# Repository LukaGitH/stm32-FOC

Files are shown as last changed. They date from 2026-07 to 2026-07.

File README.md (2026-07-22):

# Field-Oriented Control (FOC) on STM32 From Scratch

This project demonstrates a complete, low-level implementation of **Field-Oriented Control (FOC)** for controlling a **BLDC motor** using an **STM32F4 microcontroller**, without relying on high-level motor control libraries.

Built using **PlatformIO**, **STM32 HAL/LL drivers**, and **FreeRTOS**, this project is designed for learning and practical experimentation in precision motor control.

---

## Features Implemented

- Clarke & Park Transforms  
- Position feedback via AS5047 encoder  
- Phase current sampling via ADC  
- SVPWM (Space Vector PWM) generation  
- Torque Control
- Speed Control
- Position Control
- Encoder auto calibration
- Self-Commissioning for PI Gain current controller auto tuning
- Sensorless mode using Sliding Mode Observer (SMO) & High Frequency Injection (HFI)
- USB CDC interface for real-time tuning and monitoring  
- Save configuration to flash memory
- Interrupt-driven timing and FreeRTOS tasking  

---

## Development Tools

- [PlatformIO](https://platformio.org/)
- STM32CubeMX
- STM32Cube HAL & LL Drivers  
- FreeRTOS (via PlatformIO package)  
- VS Code + Serial Monitor for debugging
- KiCad 9 (hardware project in [`STM32-FOC-hardware/ESC-BLDC`](STM32-FOC-hardware/ESC-BLDC))
- Controller application source in `lib/Controller_app/` (archive:
  `controler_appv2.zip`)

---

## Simple Command Line Interface (CLI)

- change control mode: `mode <mode>`  
`<mode>`:  
  `0` -> torque/current control  
  `1` -> speed control  
  `2` -> position control  
- change set point: `sp <value>`  
- run self commissioning: `calib`  
- read motor parameters: `motor_param`  
- read all PID parameters: `pid <control>`  
`<control>`:  
  `id` -> direct current control  
  `iq` -> quadrature current control  
  `speed` -> speed control  
  `position` -> position control  
- read PID specific parameter: `pid <control> <param>`  
`<param>`:  
  `kp` -> proportional gain  
  `ki` -> integral gain  
  `kd` -> derivative gain  
  `deadband` -> error deadband (min error)  
  `max` -> max output   
- write PID parameter: `pid <control> <param> <value>`  
- save changes to flash memory: `save`  
- reset settingst: `set_default`  
- add/remove plot variable: `plot <action> <param>`  
`<action>`:  
  `add` -> add parameter to plot  
  `rm` -> remove parameter from plot  
`<param>`:  
  `ia`, `ib`, `ic` → phase current (A)  
  `i_alpha`, `i_beta` → alpha / beta current (A)  
  `id`, `iq` → d–q current (A)  
  `va`, `vb`, `vc` → phase voltage (V)  
  `v_alpha`, `v_beta` → alpha / beta voltage (V)  
  `vd`, `vq` → d–q voltage (V)  
  `v_bus` → DC bus voltage (V)  
  `rpm` → motor speed (RPM)  
  `e_rad` → electrical angle (radian)  
  `m_deg` → mechanical angle (degree)  

## Hardware and production files

The hardware project is KiCad-only. Open
[`ESC-BLDC.kicad_pro`](STM32-FOC-hardware/ESC-BLDC/ESC-BLDC.kicad_pro) in KiCad
9. The ready-to-upload JLCPCB BOM and CPL are in
[`production/export/`](STM32-FOC-hardware/ESC-BLDC/production/export/).

- [Hardware overview](STM32-FOC-hardware/README.md)
- [Production workflow and validation](STM32-FOC-hardware/ESC-BLDC/production/README.md)
- [Current component sourcing decisions](STM32-FOC-hardware/ESC-BLDC/production/component_sourcing_audit.md)
- [Symmetry and divider review](STM32-FOC-hardware/ESC-BLDC/production/symmetry_and_sourcing_review.md)
- [Original-versus-KiCad component comparison](STM32-FOC-hardware/ESC-BLDC/production/original_vs_kicad_component_comparison.csv)

## Update log

18-04-2026
- Add MTPA and Field Weakening
- Change PID constraint and anti windup algorithm
- Change voltage and current limiter algorithm in FOC

08-02-2026
- Change CLI format
- Integrate sensorless and sensored in one function and struct

03-02-2026
- Add Initial position detection with polarity judgement

20-01-2026
- Update HFI using single-bin Sliding DFT

26-11-2025
- Add sensorless mode using High Frequency Injection (HFI)
- Hysteresis switching between SMO and HFI

11-11-2025
- Add sensorless mode using Sliding Mode Observer (SMO)
- Dynamic max output PI controller Id Iq based on Vbus
- Save Rs, Ld, Lq to flash memory
- Move parse CLI code to controller_app

30-10-2025
- change algorithm to estimate resistance using constant voltage (vd)

15-10-2025
- self commissioning, auto calculate Motor Resistance and Inductance (Rs, Ld, and Lq)
- Auto Calculate PI Gain Current Control loop using R, L, and Bandwidth
- Setting bandwidth using CLI
  set_bandwidth=(bandwidth in Hz)
- move custom library code to lib folder

6-10-2025
- CAN bus
- Haptic control demo
- Setting Error Deadband and Max out PID Controler using CLI

16-9-2025
- Update audio mode

20-8-2025
- ADC injected simultaneous mode to read currents and DC voltage faster
- Add command to change title, legends, and erase graph in serial plotter

9-8-2025
- Add eccentricity calibration for magnetic encoder
- CLI for auto calibration
- Change PID manual tuning settings
- Save configuration to flash memory
- Default config

29-7-2025
- Add parity check for AS5047P

---

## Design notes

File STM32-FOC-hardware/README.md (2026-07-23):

# STM32 FOC hardware

This fork's hardware source is KiCad-only.

- Open [`ESC-BLDC/ESC-BLDC.kicad_pro`](ESC-BLDC/ESC-BLDC.kicad_pro) in KiCad 10.
- The complete schematic hierarchy and PCB are in `ESC-BLDC/`.
- Ready-to-upload JLCPCB [BOM and CPL files](ESC-BLDC/production/export/) are
  in `ESC-BLDC/production/export/`.
- [original_vs_kicad_component_comparison.csv](ESC-BLDC/production/original_vs_kicad_component_comparison.csv) is the
  reference-by-reference comparison of original Altium values/packages and the
  current KiCad selections.
- [Project Outputs for ESC-BLDC.zip](Project%20Outputs%20for%20ESC-BLDC.zip) is the existing Gerber archive, retained
  unchanged for traceability.

For component selections and the checked JLCPCB production workflow, see the
[production README](ESC-BLDC/production/README.md).

The previous Altium source files are deliberately excluded from this repository.

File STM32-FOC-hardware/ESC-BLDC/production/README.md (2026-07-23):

# STM32 FOC JLCPCB production files

The KiCad schematics and PCB are the source of truth for this production
workflow.

## Run

From the `ESC-BLDC` project directory:

```bash
python3 production/scripts/export_jlcpcb_bom.py .
python3 production/scripts/export_jlcpcb_cpl.py .
python3 production/scripts/validate_production_files.py .
python3 production/scripts/export_component_comparison.py .
```

Outputs:

- `production/export/jlcpcb_bom.csv`
- `production/export/jlcpcb_cpl.csv`
- `production/export/validation_report.txt`
- `production/original_vs_kicad_component_comparison.csv`

## Current result

- 5 schematic sheets parsed successfully
- 131 placed non-power references found, including DNP/manual items
- 118 fitted references, all with LCSC assignments
- 49 grouped JLCPCB BOM rows and 118 matching CPL rows
- 0 validation errors or warnings

The BOM exporter reads `Value`, `Footprint`, `Manufacturer`, `MPN`, `LCSC`,
`JLCPCB Class`, and `DNP`. DNP parts and power symbols are excluded.

The CPL exporter reads the KiCad component-placement file
`ESC-BLDC-all.pos`, and includes only references present in the BOM. Generate a
replacement from KiCad PCB Editor using `File > Fabrication Outputs > Component
Placement`, in millimetres and with both sides enabled.

## Original-versus-current comparison

`original_vs_kicad_component_comparison.csv` is a one-row-per-reference
spreadsheet. It preserves the imported `ALTIUM_VALUE` and package metadata next
to the current KiCad value, footprint, selected manufacturer part, LCSC code,
and assembly state.

`symmetry_and_sourcing_review.md` records the second-pass check of matched
component groups, divider ratios, and the remaining Extended selections.

## Supporting decisions

- `component_sourcing_audit.md` is the current selected-part list and records
  the order-time checks.
- `symmetry_and_sourcing_review.md` checks matched component groups, original
  package sizes, and the divider-ratio decisions.

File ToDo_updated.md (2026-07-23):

# To Do

## Schematic value display cleanup

- Change every component so the schematic displays the standard `Value` field instead of `ALTIUM_VALUE`.
- This is required because some displayed values are outdated, for example capacitors still shown as `560pF` even though their actual `Value` has changed.
- After the change, verify that the visible schematic values match each component's actual `Value` field.
- Keep the `ALTIUM_VALUE` field in the component data, but disable its visibility on the schematic.
- Enable visibility of the standard `Value` field instead.

## Connector sourcing

Use the following DigiKey parts:

- **P7, P8** — JST `SM02B-SRSS-TB`  
  DigiKey: https://www.digikey.si/en/products/detail/jst-sales-america-inc/SM02B-SRSS-TB/926708

- **P9, P10** — JST `SM04B-SRSS-TB`  
  DigiKey: https://www.digikey.si/en/products/detail/jst-sales-america-inc/SM04B-SRSS-TB/926710

- **P6** — JST `SM05B-SRSS-TB`  
  DigiKey: https://www.digikey.si/en/products/detail/jst-sales-america-inc/SM05B-SRSS-TB/926711

> **P10 note:** its existing PCB footprint is a 2.54 mm through-hole SWD
> header, not a 1.0 mm JST-SH footprint. Replacing it with
> `SM04B-SRSS-TB` requires a deliberate PCB footprint/layout change.

## Not fitted

- **R28, R29, R30** are not placed.
- Mark them as `DNP` / excluded from assembly and ensure they do not appear as fitted parts in the assembly BOM.

## Inductor verification

- **L1** — check whether the intended part is LCSC **C22463831** (`TECHFUSE SL0650-220M`).
- Verify its inductance, current ratings, dimensions, and footprint against the existing L1 schematic and PCB data before assigning it.

Verified 2026-07-23: `C22463831` is assigned as `SL0650-220M`, 22 µH, 3 A
rated current, 5 A saturation current, 98 mΩ DCR, 7.1 × 6.6 mm. It matches the
existing L1 footprint and its schematic requirements.

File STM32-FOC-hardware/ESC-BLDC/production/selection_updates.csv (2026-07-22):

Sheet | Reference | Field | Old | New | Reason
gate driver.kicad_sch | C1 | Value | 120pF | 100pF | Use stocked Basic 100pF C0G part as closest replacement for 120pF.
gate driver.kicad_sch | C1 | Description | Chip capacitor, 120pF, 10%, 16V, 0402 | 100pF 50V C0G ±5% 0402 MLCC | Use stocked Basic 100pF C0G part as closest replacement for 120pF.
gate driver.kicad_sch | C1 | Manufacturer |  | FH (Guangdong Fenghua Advanced Tech) | Use stocked Basic 100pF C0G part as closest replacement for 120pF.
gate driver.kicad_sch | C1 | MPN |  | 0402CG101J500NT | Use stocked Basic 100pF C0G part as closest replacement for 120pF.
gate driver.kicad_sch | C1 | LCSC |  | C1546 | Use stocked Basic 100pF C0G part as closest replacement for 120pF.
gate driver.kicad_sch | C1 | JLCPCB Class |  | Basic | Use stocked Basic 100pF C0G part as closest replacement for 120pF.
gate driver.kicad_sch | C1 | CASE/PACKAGE | 0402 | 0402 | Use stocked Basic 100pF C0G part as closest replacement for 120pF.
gate driver.kicad_sch | C1 | TOLERANCE | 10% | 5% | Use stocked Basic 100pF C0G part as closest replacement for 120pF.
gate driver.kicad_sch | C1 | VOLTAGE RATING | 16V | 50V | Use stocked Basic 100pF C0G part as closest replacement for 120pF.
gate driver.kicad_sch | R5 | Value | 10k | 12k | Approved stocked 12k Basic replacement for unavailable 10k selection.
gate driver.kicad_sch | R5 | Description | Chip resistor, 10k, 1%, 62.5mW, 50V, 0402 | Chip resistor, 12k, 1%, 62.5mW, 50V, 0402 | Approved stocked 12k Basic replacement for unavailable 10k selection.
gate driver.kicad_sch | R5 | Manufacturer | UNI-ROYAL(Uniroyal Elec) | UNI-ROYAL(Uniroyal Elec) | Approved stocked 12k Basic replacement for unavailable 10k selection.
gate driver.kicad_sch | R5 | MPN | 0402WGF1002TCE | 0402WGF1202TCE | Approved stocked 12k Basic replacement for unavailable 10k selection.
gate driver.kicad_sch | R5 | LCSC | C25744 | C25752 | Approved stocked 12k Basic replacement for unavailable 10k selection.
gate driver.kicad_sch | R5 | JLCPCB Class | Basic | Basic | Approved stocked 12k Basic replacement for unavailable 10k selection.
gate driver.kicad_sch | R5 | RESISTANCE |  | 12k | Approved stocked 12k Basic replacement for unavailable 10k selection.
gate driver.kicad_sch | R5 | TOLERANCE | 1% | 1% | Approved stocked 12k Basic replacement for unavailable 10k selection.
gate driver.kicad_sch | R5 | POWER | 62.5mW | 62.5mW | Approved stocked 12k Basic replacement for unavailable 10k selection.
gate driver.kicad_sch | D1 | Value | B330A-13-F | SS34 | Approved JLCPCB SS34 replacement for B330A-13-F.
gate driver.kicad_sch | D1 | Description | DIODE SCHOTTKY 30V 3A SMA | Schottky diode, 40V, 3A, SMA (DO-214AC) | Approved JLCPCB SS34 replacement for B330A-13-F.
gate driver.kicad_sch | D1 | Manufacturer |  | MDD(Microdiode Semiconductor) | Approved JLCPCB SS34 replacement for B330A-13-F.
gate driver.kicad_sch | D1 | MPN |  | SS34 | Approved JLCPCB SS34 replacement for B330A-13-F.
gate driver.kicad_sch | D1 | LCSC |  | C8678 | Approved JLCPCB SS34 replacement for B330A-13-F.
gate driver.kicad_sch | D1 | JLCPCB Class |  | Basic | Approved JLCPCB SS34 replacement for B330A-13-F.
gate driver.kicad_sch | D1 | CASE/PACKAGE |  | SMA | Approved JLCPCB SS34 replacement for B330A-13-F.
power MOSFET.kicad_sch | R12 | Value | 39k | 33k | Use stocked Basic 33k 0603 resistor for the VBUS ADC divider.
power MOSFET.kicad_sch | R12 | LCSC |  | C4216 | 0603WAF3302T5E is a stocked Basic 33k 0603 resistor.
power MOSFET.kicad_sch | R13 | Value | 2k2 | 2k | Keep the VBUS ADC divider ratio close to the original with stocked Basic 0603 parts.
power MOSFET.kicad_sch | R13 | LCSC | C4190 | C22975 | 0603WAF2001T5E is a stocked Basic 2k 0603 resistor.
lib/DRV8302_Driver/DRV8302_config.h | ADC_2_POWER_VOLT | 0.01651611328125f | 0.01409912109375f | Match the VBUS ADC conversion to the selected 33k/2k divider.
power MOSFET.kicad_sch | R23,R24 | LCSC |  | C316229 | Use the same stocked 10mΩ 1% 2W 2512 current-sense resistor for both phase shunts.
power MOSFET.kicad_sch | R23,R24 | MPN |  | RLP25FEER010 | TA-I Tech 10mΩ 1% 2W 2512 current-sense resistor.
main controller.kicad_sch | X1 | LCSC | C91581 | C2659482 | Use in-stock Murata 12MHz SMD3213-3P resonator with built-in 33pF capacitors.
main controller.kicad_sch | X1 | MPN |  | CSTNE12M0G55Z000R0 | In-stock Murata 12MHz resonator compatible with the existing 3-pad footprint.
gate driver.kicad_sch | C11 | LCSC | C49055480 | C1532 | Use stocked Basic 22nF 50V X7R 0402 part that JLCPCB matches automatically.
gate driver.kicad_sch | C11 | MPN |  | 0402B223K500NT | Use stocked Basic 22nF 50V X7R 0402 part that JLCPCB matches automatically.
gate driver.kicad_sch | C10 | Value | 2.2uF | 4.7uF | Use the user-selected stocked Basic C23733 for stronger local decoupling.
gate driver.kicad_sch | C10 | LCSC | C3870388 | C23733 | Use the user-selected stocked Basic C23733 for stronger local decoupling.
gate driver.kicad_sch | C10 | MPN |  | CL05A475MP5NRNC | Use the user-selected stocked Basic C23733 for stronger local decoupling.
gate driver.kicad_sch | L1 | LCSC | C42462944 | C22463831 | Use user-approved SL0650-220M: exact 7.1mm x 6.6mm footprint | 3A rated | 5A saturation | 98mR DCR.
gate driver.kicad_sch | L1 | MPN | ZEPI.0630A.220MT | SL0650-220M | Use user-approved SL0650-220M: exact 7.1mm x 6.6mm footprint | 3A rated | 5A saturation | 98mR DCR.
src/Core/Inc/stm32f4xx_hal_conf.h | HSE_VALUE | 16000000U | 12000000U | Match firmware clock calculations to the fitted 12MHz resonator.
main controller.kicad_sch | USB1 | LCSC |  | C3025063 | User-approved GCT USB4105-GF-A-060 right-angle 12-contact USB-C receptacle.
main controller.kicad_sch | USB1 | MPN |  | USB4105-GF-A-060 | User-approved GCT USB-C receptacle matching the A40-00119 footprint family.
ESC-BLDC.kicad_sch | P6 | MPN | BM05B-SRSS-TB(LF)(SN) | SM05B-SRSS-TB(LF)(SN) | Correct vertical top-entry selection to horizontal right-angle SMD connector with rear contact pads.
ESC-BLDC.kicad_sch | P6 | LCSC | C160391 | C136657 | Correct vertical top-entry selection to horizontal right-angle SMD connector with rear contact pads.
ESC-BLDC.kicad_sch | P7,P8 | MPN | BM02B-SRSS-TB(LF)(SN) | SM02B-SRSS-TB(LF)(SN) | Correct vertical top-entry selection to horizontal right-angle SMD connector with rear contact pads.
ESC-BLDC.kicad_sch | P7,P8 | LCSC | C160388 | C160402 | Correct vertical top-entry selection to horizontal right-angle SMD connector with rear contact pads.
ESC-BLDC.kicad_sch | P9 | MPN | BM04B-SRSS-TB(LF)(SN) | SM04B-SRSS-TB(LF)(SN) | Correct vertical top-entry selection to horizontal right-angle SMD connector with rear contact pads.
ESC-BLDC.kicad_sch | P9 | LCSC | C160390 | C160404 | Correct vertical top-entry selection to horizontal right-angle SMD connector with rear contact pads.
ESC-BLDC.kicad_sch | P6,P7,P8,P9 | DNP |  | Yes | Do not assemble connector footprints; leave pads available for a future correctly oriented manual solution.
ESC-BLDC.kicad_sch | C42 | Value | 560pF | 220pF | Match C41 in the symmetric CAN-H/CAN-L 120ohm RC filter while using stocked Basic C1530.
ESC-BLDC.kicad_sch | C42 | Description | Chip capacitor; 560pF; 10%; 50V; 0402 | 220pF 50V X7R ±10% 0402 MLCC | Match C41 in the symmetric CAN-H/CAN-L 120ohm RC filter while using stocked Basic C1530.
ESC-BLDC.kicad_sch | C42 | LCSC | C778322 | C1530 | Match C41 in the symmetric CAN-H/CAN-L 120ohm RC filter while using stocked Basic C1530.
ESC-BLDC.kicad_sch | C42 | MPN |  | 0402B221K500NT | Match C41 in the symmetric CAN-H/CAN-L 120ohm RC filter while using stocked Basic C1530.
gate driver.kicad_sch | D1 | WORKING REVERSE VOLTAGE | 30V | 40V | Approved JLCPCB SS34 replacement for B330A-13-F.
main controller.kicad_sch | DS2 | Value | LTST-C190KSKT | KT-0603R | Approved Basic 0603 red LED replacement.
main controller.kicad_sch | DS2 | Description | LED Uni-Color Yellow, 75 mW, 30 mA, -30 to 85 degC, 2-Pin SMD, RoHS, Tape and Reel | Red water-clear LED, 0603, 20mA, 1.8V to 2.4V | Approved Basic 0603 red LED replacement.
main controller.kicad_sch | DS2 | Manufacturer |  | Hubei KENTO Elec | Approved Basic 0603 red LED replacement.
main controller.kicad_sch | DS2 | MPN |  | KT-0603R | Approved Basic 0603 red LED replacement.
main controller.kicad_sch | DS2 | LCSC |  | C2286 | Approved Basic 0603 red LED replacement.
main controller.kicad_sch | DS2 | JLCPCB Class |  | Basic | Approved Basic 0603 red LED replacement.
main controller.kicad_sch | DS2 | CASE/PACKAGE | 0603 | 0603 | Approved Basic 0603 red LED replacement.
main controller.kicad_sch | DS2 | FORWARD CURRENT | 20mA | 20mA | Approved Basic 0603 red LED replacement.
main controller.kicad_sch | DS2 | POWER | 75mW | 40mW | Approved Basic 0603 red LED replacement.
main controller.kicad_sch | D12 | Value | 1N4007 SMD | M7 | Selected SMD 1N4007-equivalent in SMA package.
main controller.kicad_sch | D12 | Description | Rectifier, 1Kv, 1A, Do-214Ac Rohs Compliant: Yes | General-purpose rectifier diode, 1kV, 1A, SMA | Selected SMD 1N4007-equivalent in SMA package.
main controller.kicad_sch | D12 | Manufacturer |  | Shenzhen Jinkaisheng Elec | Selected SMD 1N4007-equivalent in SMA package.
main controller.kicad_sch | D12 | MPN |  | 1N4007(M7)SMA | Selected SMD 1N4007-equivalent in SMA package.
main controller.kicad_sch | D12 | LCSC |  | C2972759 | Selected SMD 1N4007-equivalent in SMA package.
main controller.kicad_sch | D12 | JLCPCB Class |  | Extended | Selected SMD 1N4007-equivalent in SMA package.
main controller.kicad_sch | D12 | CASE/PACKAGE |  | SMA | Selected SMD 1N4007-equivalent in SMA package.
ESC-BLDC.kicad_sch | C41 | Value | 560pF | 220pF | User-selected C1530; verified code is 220pF, not 2200pF.
ESC-BLDC.kicad_sch | C41 | Description | Chip capacitor, 560pF, 10%, 50V, 0402 | 220pF 50V X7R ±10% 0402 MLCC | User-selected C1530; verified code is 220pF, not 2200pF.
ESC-BLDC.kicad_sch | C41 | Manufacturer |  | FH (Guangdong Fenghua Advanced Tech) | User-selected C1530; verified code is 220pF, not 2200pF.
ESC-BLDC.kicad_sch | C41 | MPN |  | 0402B221K500NT | User-selected C1530; verified code is 220pF, not 2200pF.
ESC-BLDC.kicad_sch | C41 | LCSC |  | C1530 | User-selected C1530; verified code is 220pF, not 2200pF.
ESC-BLDC.kicad_sch | C41 | JLCPCB Class |  | Basic | User-selected C1530; verified code is 220pF, not 2200pF.
ESC-BLDC.kicad_sch | C41 | CASE/PACKAGE | 0402 | 0402 | User-selected C1530; verified code is 220pF, not 2200pF.
ESC-BLDC.kicad_sch | C41 | TOLERANCE | 10% | 10% | User-selected C1530; verified code is 220pF, not 2200pF.
ESC-BLDC.kicad_sch | C41 | VOLTAGE RATING | 50V | 50V | User-selected C1530; verified code is 220pF, not 2200pF.
gate driver.kicad_sch | J1 | DNP |  | Yes | Solder bridge, not a purchased or assembled component.
gate driver.kicad_sch | J1 | Description | JUMPER | Solder jumper; not a fitted component | Solder bridge, not a purchased or assembled component.
gate driver.kicad_sch | J1 | JLCPCB Class |  | Not assembled | Solder bridge, not a purchased or assembled component.
gate driver.kicad_sch | J1 | in_bom | yes | no | Solder bridge, not a purchased or assembled component.
gate driver.kicad_sch | J1 | in_pos_files | yes | no | Solder bridge, not a purchased or assembled component.
gate driver.kicad_sch | J1 | dnp | no | yes | Solder bridge, not a purchased or assembled component.
gate driver.kicad_sch | J2 | DNP |  | Yes | Solder bridge, not a purchased or assembled component.
gate driver.kicad_sch | J2 | Description | JUMPER | Solder jumper; not a fitted component | Solder bridge, not a purchased or assembled component.
gate driver.kicad_sch | J2 | JLCPCB Class |  | Not assembled | Solder bridge, not a purchased or assembled component.
gate driver.kicad_sch | J2 | in_bom | yes | no | Solder bridge, not a purchased or assembled component.
gate driver.kicad_sch | J2 | in_pos_files | yes | no | Solder bridge, not a purchased or assembled component.
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

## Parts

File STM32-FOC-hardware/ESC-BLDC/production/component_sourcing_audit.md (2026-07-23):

# Component sourcing audit — 2026-07-22

This audit separates verified JLCPCB purchasing selections from parts that need
an electrical-design decision or are presently unavailable. It does not change
the KiCad source files while the project is open in KiCad.

## Ready to apply

| References | Design value / required package | Selected manufacturer part | LCSC | JLCPCB status |
|---|---|---|---|---|
| D2 | 1N4148WS, SOD-323 | 1N4148WS (Jiangsu Changjing) | C2128 | In stock |
| D3–D11 | 1N4148WT, SOD-523 | 1N4148WT (JSMSEMI) | C917006 | In stock |
| U2 | LP2985-33DBVR, SOT-23-5 / DBV | LP2985-33DBVR (Texas Instruments) | C95414 | In stock |
| U6 | STM32F405RGT6, LQFP-64 10 × 10 mm | STM32F405RGT6 (STMicroelectronics) | C15742 | Verify live stock at order placement |
| C10 | 4.7 µF, 10 V, 0402 | CL05A475MP5NRNC (Samsung), X5R ±20% | C23733 | Basic, in stock |
| C11 | 22 nF, 50 V, 0402 | 0402B223K500NT (FH), X7R ±10% | C1532 | Basic, in stock |
| C32 | 10 nF, 50 V, 0402 | CL05B103KB5NNNC (Samsung), X7R ±10% | C15195 | Basic |

The diode selections retain the existing diode families and footprints. U2 and
U6 are exact manufacturer-part matches, not replacements.

## IC sourcing selections

| Reference | Selected part | LCSC | Decision |
|---|---|---|---|
| U1 | TI DRV8302DCA, HTSSOP-56 | C84672 | Exact manufacturer part. |
| U3 | AMS AS5047P-ATSM, TSSOP-14 | C962063 | Exact manufacturer part. |
| U4 | JSMSEMI MCP2551-I/SN-JSM, SOP-8 | C46596284 | 5 V, 1 Mb/s MCP2551-compatible CAN transceiver. |
| U5 | ST USBLC6-2SC6Y, SOT-23-6L | C2969755 | Exact manufacturer part; JLC may require an assembly fixture. |
| X1 | Murata CSTNE12M0G55Z000R0, SMD3213-3P | C2659482 | Selected 12 MHz resonator; verify live stock at order placement. |

## Connector sourcing selections

| References | Selected part | LCSC | Decision |
|---|---|---|---|
| P1, P2 | Amass XT30PW-M30.G.Y | C431092 | 2-pin male XT30 power connector; verify pad geometry against the board footprint before ordering. |

## Manual connector sourcing

These connectors remain DNP in the JLCPCB BOM/CPL and are to be bought and
fitted manually.

| References | Selected JST part | Source |
|---|---|---|
| P7, P8 | SM02B-SRSS-TB, 2-position, 1.0 mm, right-angle SMD | DigiKey 926708 |
| P9 | SM04B-SRSS-TB, 4-position, 1.0 mm, right-angle SMD | DigiKey 926710 |
| P6 | SM05B-SRSS-TB, 5-position, 1.0 mm, right-angle SMD | DigiKey 926711 |

P10 remains an unpopulated 2.54 mm through-hole SWD header. It cannot use the
SM04B-SRSS-TB without replacing its PCB footprint and revising the layout.

## Requires circuit decision before sourcing

- R7/R8: DRV8302 OC_ADJ divider selected for an approximately 20 A hot-device
  trip target: R7/RA = 39 kΩ (`C163424`, 0603, Extended), R8/RB = 1 kΩ
  (`C21190`, 0603, Basic). The second-pass review found no verified Basic
  39 kΩ 0603 replacement. Retain this pair: changing R7 alone to 36 kΩ would
  raise the OC_ADJ threshold by 8.1%; changing both to 36 kΩ / 910 Ω would
  keep it within 1.4%, but does not remove the order's Extended-part setup
  because L1, the MOSFETs, and specialised parts remain Extended. Both J1 and
  J2 solder bridges must be closed to connect the divider to OC_ADJ.
- R12/R13: VBUS ADC divider selected as 33 kΩ / 2 kΩ, both 0603 Basic parts
  (`C4216` / `C22975`). Firmware conversion is set to 0.01409912109375 V per
  ADC count for this divider.
- R23/R24: selected TA-I Tech RLP25FEER010, 10 mΩ, 1%, 2 W, 2512
  (`C316229`, Extended). Firmware remains calibrated for 10 mΩ. At 20 A RMS a
  shunt dissipates 4 W, exceeding this component's continuous rating.
- L1: selected SL0650-220M, 22 µH, 3 A rated, 5 A saturation, 98 mΩ,
  7.1 × 6.6 mm (`C22463831`). Exact land-pattern size match to the existing footprint.
- X1: selected Murata CSTNE12M0G55Z000R0, 12 MHz, 30 Ω, 33 pF built-in
  capacitors, SMD3213-3P (`C2659482`, Extended). Firmware HSE_VALUE is 12 MHz.
- USB1: selected GCT USB4105-GF-A-060, USB 2.0 Type-C receptacle, 12 contact,
  right-angle top mount with shell stakes (`C3025063`, Extended). Confirmed by
  user against the existing A40-00119 footprint.

## Excluded by design

J1 and J2 are solder jumpers. P3, P4, and P5 are solder pads; R28–R30 are
unpopulated zero-ohm links; P6–P9 are unpopulated connector footprints; and
P10 is not fitted. They are DNP/not in BOM and need no LCSC purchase assignment.

## CAN filter matching

| References | Selected part | LCSC | Decision |
|---|---|---|---|
| C41, C42 | 220 pF, 50 V, X7R ±10%, 0402 | C1530 | Matched pair for the CAN-H/CAN-L RC filter; Basic and in stock at review. |

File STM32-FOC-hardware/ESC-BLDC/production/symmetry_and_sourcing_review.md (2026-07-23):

# Symmetry and sourcing review — 2026-07-22

This is a second pass over the 118 fitted references in the KiCad production
package. The source comparison spreadsheet remains the one-to-one record of
every original Altium reference, value, package, and current KiCad selection:
`original_vs_kicad_component_comparison.csv`.

## Result

- All 118 fitted references have an LCSC assignment and corresponding CPL row.
- All repeated phase-channel components use the same value, footprint, and LCSC
  selection within their group.
- The KiCad footprints preserve the original nominal package sizes for the
  reviewed passives: 0402, 0603, 2512, and the 2525 inductor land pattern.
- P6–P9 remain intentionally DNP because the available JST-style parts did not
  provide the required rear-facing SMD contact geometry.

## Matched electrical groups

| References | Function | Current selection | Review result |
|---|---|---|---|
| Q1–Q6 | Three half bridges | FDMS8820, `C236897`, PDFN56 | Six identical MOSFETs. Keep the selected Extended part. |
| R14–R16, R20–R22 | Gate resistors | 10 Ω, 0603, `C22859` | Six identical parts. |
| R17–R19 | Phase-voltage divider upper legs | 33 kΩ, 0402, `C25779` | Three identical parts. |
| R25–R27 | Phase-voltage divider lower legs | 2 kΩ, 0402, `C4109` | Three identical Basic parts; MPN corrected to `0402WGF2001TCE`. |
| R23, R24 | Phase-current shunts | 10 mΩ, 2512, `C316229` | Matched pair. |
| C41, C42 | CAN filter capacitors | 220 pF, 0402, `C1530` | Matched pair. |
| C33–C35 | Bulk ceramic decoupling | 2.2 µF, 0603, `C23630` | Matched trio. |
| D3–D11 | Signal diodes | 1N4148WT, SOD-523, `C917006` | Matched nine-part group. |
| P1, P2 | Power connectors | XT30PW-M, `C431092` | Matched pair. |

## Divider check

### Phase-voltage and VBUS dividers

Each phase-voltage divider is 33 kΩ / 2 kΩ (R17/R25, R18/R26, and R19/R27),
giving a divider factor of 2 / (33 + 2) = **0.05714**. These are symmetric and
already use Basic resistors.

The VBUS divider R12/R13 is also 33 kΩ / 2 kΩ, using 0603 Basic selections
`C4216` and `C22975`. Its factor is therefore the same. Firmware has already
been set to the matching conversion constant; changing either VBUS resistor
requires updating that firmware constant.

### DRV8302 OC_ADJ divider

R7/R8 is 39 kΩ / 1 kΩ, so:

`V_OC_ADJ = 3.3 V × 1 / (39 + 1) = 82.5 mV`.

This is a hardware current-limit threshold, not a firmware scaling factor.
Changing only R7 to a nearby 36 kΩ Basic candidate would produce 89.2 mV,
an **8.1% higher** current trip. Changing the pair to 36 kΩ / 910 Ω would
produce 81.3 mV, **1.4% lower** than the current design, but the exact proposed
Basic stock pair needs confirmation at order time.

Recommendation: retain 39 kΩ `C163424` and 1 kΩ `C21190`. One Extended resistor
does not avoid Extended-part handling on this board because L1, the power
MOSFETs, and specialised IC/connector selections already require it.

## Remaining Extended selections

| References | Part | Why it remains |
|---|---|---|
| L1 | 22 µH SL0650-220M, `C22463831` | Correct 7.1 × 6.6 mm footprint, current rating, and saturation-current requirement. |
| Q1–Q6 | FDMS8820, `C236897` | Power MOSFET electrical and package match. |
| D12 | M7 / 1N4007 SMA, `C2972759` | 1 kV rectifier requirement; do not replace with a lower-voltage Basic diode. |
| R7 | 39 kΩ 0603, `C163424` | Exact OC_ADJ ratio. A Basic substitution shifts hardware over-current trip unless the pair is redesigned. |
| X1, USB1, ICs, P1/P2 | Specialised package-specific parts | No passive Basic substitution is applicable. |

## Deliberate value changes from the imported design

The comparison spreadsheet records 40 value-text differences. Most are
notation normalisation (`µF` to `uF`) or already-approved sourcing changes.
The electrically relevant reviewed changes are C10 (4.7 µF), C11 (22 nF),
C41/C42 (220 pF matched pair), the 33 kΩ / 2 kΩ phase and VBUS divider groups,
and the 39 kΩ / 1 kΩ OC_ADJ pair. No additional value changes are recommended
by this review.

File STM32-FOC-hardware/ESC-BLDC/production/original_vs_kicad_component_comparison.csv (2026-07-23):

Sheet | Reference | Original Altium value | Original package | Current KiCad value | Current KiCad footprint | Selected MPN | LCSC part | JLCPCB class | Assembly status | Value changed
ESC-BLDC.kicad_sch | C41 | 560pF(0402) | 0402 | 220pF | CAPC0402(1005)60_L | 0402B221K500NT | C1530 | Basic | Fitted | Yes
ESC-BLDC.kicad_sch | C42 | 560pF(0402) | 0402 | 220pF | CAPC0402(1005)60_L | 0402B221K500NT | C1530 | Basic | Fitted | Yes
ESC-BLDC.kicad_sch | C43 | 100nF(0402) | 0402 | 100nF | CAPC0402(1005)60_L | CL05B104KB54PNC | C307331 | Basic | Fitted | No
ESC-BLDC.kicad_sch | P7 | SM02B-SRSS-TB |  | SM02B-SRSS-TB | SH-2P-SIDE | SM02B-SRSS-TB |  |  | DNP / manual | No
ESC-BLDC.kicad_sch | P8 | SM02B-SRSS-TB |  | SM02B-SRSS-TB | SH-2P-SIDE | SM02B-SRSS-TB |  |  | DNP / manual | No
ESC-BLDC.kicad_sch | R31 | 100R(0402) | 0402 | 100R | RESC1005X40X25ML05T05 | 0402WGF1000TCE | C25076 | Basic | Fitted | No
ESC-BLDC.kicad_sch | R32 | 120R | 0603 | 120R | FP-RMCF0603-IPC_A |  | C22787 |  | Fitted | No
ESC-BLDC.kicad_sch | R33 | 100R(0402) | 0402 | 100R | RESC1005X40X25ML05T05 | 0402WGF1000TCE | C25076 | Basic | Fitted | No
ESC-BLDC.kicad_sch | R34 | 4k7(0402) | 0402 | 4k7 | RESC1005X40X25ML05T05 | 0402WGF4701TCE | C25900 | Basic | Fitted | No
ESC-BLDC.kicad_sch | U4 | MCP2551-I/SN |  | MCP2551-I/SN | MCHP-SN8_V | MCP2551-I/SN-JSM | C46596284 |  | Fitted | No
gate driver.kicad_sch | C1 | 120pF | 0402 | 100pF | CAPC1005X56X25NL10T15 | 0402CG101J500NT | C1546 | Basic | Fitted | Yes
gate driver.kicad_sch | C2 | 6.8nF | 0402 | 10nF | CAPC1005X56X25NL10T15 | CL05B103KB5NNNC | C15195 | Basic | Fitted | Yes
gate driver.kicad_sch | C3 | 15nF | 0402 | 10nF | CAPC0402(1005)60_L | CL05B103KB5NNNC | C15195 | Basic | Fitted | Yes
gate driver.kicad_sch | C4 | 100nF | 0603 | 100nF | CAPC1608X90X40NL10T20 | CC0603KRX7R9BB104 | C14663 | Basic | Fitted | No
gate driver.kicad_sch | C5 | 4.7µF | 0603 | 4.7uF | CAPC0603(1608)100_L | CL10A475KO8NNNC | C19666 | Basic | Fitted | Yes
gate driver.kicad_sch | C6 | 100nF | 0603 | 100nF | CAPC1608X90X40NL10T20 | CC0603KRX7R9BB104 | C14663 | Basic | Fitted | No
gate driver.kicad_sch | C7 | 100nF | 0603 | 100nF | CAPC1608X90X40NL10T20 | CC0603KRX7R9BB104 | C14663 | Basic | Fitted | No
gate driver.kicad_sch | C8 | 47µF | 0805 | 47uF | CAPC0805(2012)145_L | CL21A476MQYNNNE | C16780 | Basic | Fitted | Yes
gate driver.kicad_sch | C9 | 100nF | 0603 | 100nF | CAPC1608X90X40NL10T20 | CC0603KRX7R9BB104 | C14663 | Basic | Fitted | No
gate driver.kicad_sch | C10 | 2.2µF | 0402 | 4.7uF | CAPC0402(1005)60_L | CL05A475MP5NRNC | C23733 | Basic | Fitted | Yes
gate driver.kicad_sch | C11 | 22nF | 0402 | 22nF | CAPC0402(1005)60_L | 0402B223K500NT | C1532 | Basic | Fitted | No
gate driver.kicad_sch | C12 | 100nF | 0603 | 100nF | CAPC1608X90X40NL10T20 | CC0603KRX7R9BB104 | C14663 | Basic | Fitted | No
gate driver.kicad_sch | C13 | 1µF | 0402 | 1uF | CAPC0402(1005)60_L | CL05A105KA5NQNC | C52923 | Basic | Fitted | Yes
gate driver.kicad_sch | C14 | 1µF | 0402 | 1uF | CAPC0402(1005)60_L | CL05A105KA5NQNC | C52923 | Basic | Fitted | Yes
gate driver.kicad_sch | C15 | 100nF | 0603 | 100nF | CAPC1608X90X40NL10T20 | CC0603KRX7R9BB104 | C14663 | Basic | Fitted | No
gate driver.kicad_sch | C16 | 4.7µF | 0603 | 4.7uF | CAPC0603(1608)100_L | CL10A475KO8NNNC | C19666 | Basic | Fitted | Yes
gate driver.kicad_sch | C17 | 2.2nF | 0402 | 1nF | CAPC0402(1005)60_L | 0402B102K500NT | C1523 | Basic | Fitted | Yes
gate driver.kicad_sch | C18 | 2.2nF | 0402 | 1nF | CAPC0402(1005)60_L | 0402B102K500NT | C1523 | Basic | Fitted | Yes
gate driver.kicad_sch | D1 | 200pF | SMA | SS34 | FP-SMA-MFG | SS34 | C8678 | Basic | Fitted | Yes
gate driver.kicad_sch | J1 | JUMPER |  | JUMPER | JUMPER |  |  | Not assembled | DNP / manual | No
gate driver.kicad_sch | J2 | JUMPER |  | JUMPER | JUMPER |  |  | Not assembled | DNP / manual | No
gate driver.kicad_sch | L1 | 22uH | 2525 | 22uH | FP-IHLP-2525CZ-FP_2_413x3-MFG | SL0650-220M | C22463831 |  | Fitted | No
gate driver.kicad_sch | R1 | 15k | 0402 | 15k | RESC1005X40X25ML10T10 | 0402WGF1502TCE | C25756 | Basic | Fitted | No
gate driver.kicad_sch | R2 | 18k | 0603 | 18k | RESC1608X55X25ML10T15 | 0603WAF1802T5E | C25810 | Basic | Fitted | No
gate driver.kicad_sch | R3 | 200k | 0402 | 200k | RESC0402(1005)_L | 0402WGF2003TCE | C25764 | Basic | Fitted | No
gate driver.kicad_sch | R4 | 3k3 | 0603 | 3k3 | RESC1608X55X25ML10T15 | 0603WAF3301T5E | C22978 | Basic | Fitted | No
gate driver.kicad_sch | R5 | 10k | 0402 | 12k | RESC1005X40X25ML05T05 | 0402WGF1202TCE | C25752 | Basic | Fitted | Yes
gate driver.kicad_sch | R6 | 1M | 0603 | 1M | RESC1608X55X25ML10T15 |  | C22935 |  | Fitted | No
gate driver.kicad_sch | R7 | RA | 0603 | 39k | RESC1608X55X25ML10T15 | RC0603FR-0739KL | C163424 |  | Fitted | Yes
gate driver.kicad_sch | R8 | RB | 0603 | 1k | RESC1608X55X25ML10T15 | 0603WAF1001T5E | C21190 |  | Fitted | Yes
gate driver.kicad_sch | R9 | 56R | 0402 | 100R | RESC1005X40X25ML05T05 | 0402WGF1000TCE | C25076 | Basic | Fitted | Yes
gate driver.kicad_sch | R10 | 56R | 0402 | 100R | RESC1005X40X25ML05T05 | 0402WGF1000TCE | C25076 | Basic | Fitted | Yes
gate driver.kicad_sch | U1 | DRV8302DCA |  | DRV8302DCA | HTSSOP-56 | DRV8302DCA | C84672 |  | Fitted | No
main controller.kicad_sch | C44 | 100nF(0402) | 0402 | 100nF | CAPC0402(1005)60_L | CL05B104KB54PNC | C307331 | Basic | Fitted | No
main controller.kicad_sch | C45 | 100nF(0402) | 0402 | 100nF | CAPC0402(1005)60_L | CL05B104KB54PNC | C307331 | Basic | Fitted | No
main controller.kicad_sch | C46 | 100nF(0402) | 0402 | 100nF | CAPC0402(1005)60_L | CL05B104KB54PNC | C307331 | Basic | Fitted | No
main controller.kicad_sch | C47 | 100nF(0402) | 0402 | 100nF | CAPC0402(1005)60_L | CL05B104KB54PNC | C307331 | Basic | Fitted | No
main controller.kicad_sch | C48 | 100nF(0402) | 0402 | 100nF | CAPC0402(1005)60_L | CL05B104KB54PNC | C307331 | Basic | Fitted | No
main controller.kicad_sch | C49 | 100nF(0402) | 0402 | 100nF | CAPC0402(1005)60_L | CL05B104KB54PNC | C307331 | Basic | Fitted | No
main controller.kicad_sch | C50 | 100nF(0402) | 0402 | 100nF | CAPC0402(1005)60_L | CL05B104KB54PNC | C307331 | Basic | Fitted | No
main controller.kicad_sch | C51 | 100nF(0402) | 0402 | 100nF | CAPC0402(1005)60_L | CL05B104KB54PNC | C307331 | Basic | Fitted | No
main controller.kicad_sch | D12 | M7 | SMA | M7 | FP-1N4007_SMD-IPC_A | 1N4007(M7)SMA | C2972759 | Extended | Fitted | No
main controller.kicad_sch | DS2 | KT-0603R | 0603 | KT-0603R | LTST-C190KSKT_V | KT-0603R | C2286 | Basic | Fitted | No
main controller.kicad_sch | P9 | SM04B-SRSS-TB |  | SM04B-SRSS-TB | SH-04-SIDE | SM04B-SRSS-TB |  |  | DNP / manual | No
main controller.kicad_sch | P10 | HEADER-4P |  | HEADER-4P | female_header-4p |  |  |  | DNP / manual | No
main controller.kicad_sch | R35 | 100R(0402) | 0402 | 100R | RESC1005X40X25ML05T05 | 0402WGF1000TCE | C25076 | Basic | Fitted | No
main controller.kicad_sch | R36 | 100R(0402) | 0402 | 100R | RESC1005X40X25ML05T05 | 0402WGF1000TCE | C25076 | Basic | Fitted | No
main controller.kicad_sch | R37 | 12k(0402) | 0402 | 12k | RESC1005X40X25ML05T05 | 0402WGF1202TCE | C25752 | Basic | Fitted | No
main controller.kicad_sch | R38 | 12k(0402) | 0402 | 12k | RESC1005X40X25ML05T05 | 0402WGF1202TCE | C25752 | Basic | Fitted | No
main controller.kicad_sch | R39 | 1k(0402) | 0402 | 1k | RESC1005X40X25ML05T05 | 0402WGF1001TCE | C11702 | Basic | Fitted | No
main controller.kicad_sch | U5 | USBLC6-2SC6Y |  | USBLC6-2SC6Y | SOT23-6 | USBLC6-2SC6Y | C2969755 |  | Fitted | No
main controller.kicad_sch | U6 | STM32F405RGT6 |  | STM32F405RGT6 | QFP50P1200X1200X160-64N |  | C15742 |  | Fitted | No
main controller.kicad_sch | USB1 | USB-C |  | USB-C | USB-C-A40-00119 | USB4105-GF-A-060 | C3025063 |  | Fitted | No
main controller.kicad_sch | X1 | 12MHz |  | 12MHz | MURA-CSTCE_G_V | CSTNE12M0G55Z000R0 | C2659482 |  | Fitted | No
power MOSFET.kicad_sch | C19 | 10µF | 0805 | 10uF | CAPC2013X135X45NL10T25 | CL21A106KAYNNNE | C15850 | Basic | Fitted | Yes
power MOSFET.kicad_sch | C20 | 10µF | 0805 | 10uF | CAPC2013X135X45NL10T25 | CL21A106KAYNNNE | C15850 | Basic | Fitted | Yes
power MOSFET.kicad_sch | C21 | 10µF | 0805 | 10uF | CAPC2013X135X45NL10T25 | CL21A106KAYNNNE | C15850 | Basic | Fitted | Yes
power MOSFET.kicad_sch | C22 | 10µF | 0805 | 10uF | CAPC2013X135X45NL10T25 | CL21A106KAYNNNE | C15850 | Basic | Fitted | Yes
power MOSFET.kicad_sch | C23 | 10µF | 0805 | 10uF | CAPC2013X135X45NL10T25 | CL21A106KAYNNNE | C15850 | Basic | Fitted | Yes
power MOSFET.kicad_sch | C24 | 10µF | 0805 | 10uF | CAPC2013X135X45NL10T25 | CL21A106KAYNNNE | C15850 | Basic | Fitted | Yes
power MOSFET.kicad_sch | C25 | 10µF | 0805 | 10uF | CAPC2013X135X45NL10T25 | CL21A106KAYNNNE | C15850 | Basic | Fitted | Yes
power MOSFET.kicad_sch | C26 | 10µF | 0805 | 10uF | CAPC2013X135X45NL10T25 | CL21A106KAYNNNE | C15850 | Basic | Fitted | Yes
power MOSFET.kicad_sch | C27 | 10µF | 0805 | 10uF | CAPC2013X135X45NL10T25 | CL21A106KAYNNNE | C15850 | Basic | Fitted | Yes
power MOSFET.kicad_sch | C28 | 10µF | 0805 | 10uF | CAPC2013X135X45NL10T25 | CL21A106KAYNNNE | C15850 | Basic | Fitted | Yes
power MOSFET.kicad_sch | C29 | 1µF | 0603 | 1uF | CAPC1608X90X35ML15T15 | CL10A105KB8NNNC | C15849 | Basic | Fitted | Yes
power MOSFET.kicad_sch | C30 | 2.2µF | 0603 | 2.2uF | CAPC1608X90X35ML15T15 | CL10A225KO8NNNC | C23630 | Basic | Fitted | Yes
power MOSFET.kicad_sch | C31 | 100nF | 0402 | 100nF | CAPC0402(1005)60_L | CL05B104KB54PNC | C307331 | Basic | Fitted | No
power MOSFET.kicad_sch | C32 | 10nF | 0402 | 10nF | CAPC0402(1005)60_L |  | C15195 |  | Fitted | No
power MOSFET.kicad_sch | C33 | 2.2µF | 0603 | 2.2uF | CAPC0603(1608)100_L | CL10A225KO8NNNC | C23630 | Basic | Fitted | Yes
power MOSFET.kicad_sch | C34 | 2.2µF | 0603 | 2.2uF | CAPC0603(1608)100_L | CL10A225KO8NNNC | C23630 | Basic | Fitted | Yes
power MOSFET.kicad_sch | C35 | 2.2µF | 0603 | 2.2uF | CAPC0603(1608)100_L | CL10A225KO8NNNC | C23630 | Basic | Fitted | Yes
power MOSFET.kicad_sch | C36 | 100nF | 0402 | 100nF | CAPC0402(1005)60_L | CL05B104KB54PNC | C307331 | Basic | Fitted | No
power MOSFET.kicad_sch | C37 | 100nF | 0402 | 100nF | CAPC0402(1005)60_L | CL05B104KB54PNC | C307331 | Basic | Fitted | No
power MOSFET.kicad_sch | C38 | 100nF | 0402 | 100nF | CAPC0402(1005)60_L | CL05B104KB54PNC | C307331 | Basic | Fitted | No
power MOSFET.kicad_sch | D2 | 1N4148WS | SOD-323 | 1N4148WS | FAIR-SOD-323_V |  | C2128 |  | Fitted | No
power MOSFET.kicad_sch | D3 | 1N4148WT |  | 1N4148WT | FAIR-SOD-523F-2_V |  | C917006 |  | Fitted | No
power MOSFET.kicad_sch | D4 | 1N4148WT |  | 1N4148WT | FAIR-SOD-523F-2_V |  | C917006 |  | Fitted | No
power MOSFET.kicad_sch | D5 | 1N4148WT |  | 1N4148WT | FAIR-SOD-523F-2_V |  | C917006 |  | Fitted | No
power MOSFET.kicad_sch | D6 | 1N4148WT |  | 1N4148WT | FAIR-SOD-523F-2_V |  | C917006 |  | Fitted | No
power MOSFET.kicad_sch | D7 | 1N4148WT |  | 1N4148WT | FAIR-SOD-523F-2_V |  | C917006 |  | Fitted | No
power MOSFET.kicad_sch | D8 | 1N4148WT |  | 1N4148WT | FAIR-SOD-523F-2_V |  | C917006 |  | Fitted | No
power MOSFET.kicad_sch | D9 | 1N4148WT |  | 1N4148WT | FAIR-SOD-523F-2_V |  | C917006 |  | Fitted | No
power MOSFET.kicad_sch | D10 | 1N4148WT |  | 1N4148WT | FAIR-SOD-523F-2_V |  | C917006 |  | Fitted | No
power MOSFET.kicad_sch | D11 | 1N4148WT |  | 1N4148WT | FAIR-SOD-523F-2_V |  | C917006 |  | Fitted | No
power MOSFET.kicad_sch | DS1 | KT-0603R | 0603 | KT-0603R | AVAG-HSMX-C190_V | KT-0603R | C2286 | Basic | Fitted | No
power MOSFET.kicad_sch | P1 | XT30PW-M |  | XT30PW-M | XT30PW-M | XT30PW-M30.G.Y | C431092 |  | Fitted | No
power MOSFET.kicad_sch | P2 | XT30PW-M |  | XT30PW-M | XT30PW-M | XT30PW-M30.G.Y | C431092 |  | Fitted | No
power MOSFET.kicad_sch | P3 | DP-01 |  | DP-01 | DP-01 |  |  |  | DNP / manual | No
power MOSFET.kicad_sch | P4 | DP-01 |  | DP-01 | DP-01 |  |  | Not assembled | DNP / manual | No
power MOSFET.kicad_sch | P5 | DP-01 |  | DP-01 | DP-01 |  |  |  | DNP / manual | No
power MOSFET.kicad_sch | Q1 | FDMS8820 | Power-56 | FDMS8820 | PDFN56 | FDMS8820 | C236897 | Extended | Fitted | No
power MOSFET.kicad_sch | Q2 | FDMS8820 | Power-56 | FDMS8820 | PDFN56 | FDMS8820 | C236897 | Extended | Fitted | No
power MOSFET.kicad_sch | Q3 | FDMS8820 | Power-56 | FDMS8820 | PDFN56 | FDMS8820 | C236897 | Extended | Fitted | No
power MOSFET.kicad_sch | Q4 | FDMS8820 | Power-56 | FDMS8820 | PDFN56 | FDMS8820 | C236897 | Extended | Fitted | No
power MOSFET.kicad_sch | Q5 | FDMS8820 | Power-56 | FDMS8820 | PDFN56 | FDMS8820 | C236897 | Extended | Fitted | No
power MOSFET.kicad_sch | Q6 | FDMS8820 | Power-56 | FDMS8820 | PDFN56 | FDMS8820 | C236897 | Extended | Fitted | No
power MOSFET.kicad_sch | R11 | 1k(0402) | 0402 | 1k | RESC1005X40X25ML05T05 | 0402WGF1001TCE | C11702 | Basic | Fitted | No
power MOSFET.kicad_sch | R12 | 33k | 0603 | 33k | RESC1608X55X25ML10T15 | 0603WAF3302T5E | C4216 |  | Fitted | No
power MOSFET.kicad_sch | R13 | 2k | 0603 | 2k | RESC1608X55X25ML10T15 | 0603WAF2001T5E | C22975 |  | Fitted | No
power MOSFET.kicad_sch | R14 | 10R | 0603 | 10R | RESC0603(1608)_L |  | C22859 |  | Fitted | No
power MOSFET.kicad_sch | R15 | 10R | 0603 | 10R | RESC0603(1608)_L |  | C22859 |  | Fitted | No
power MOSFET.kicad_sch | R16 | 10R | 0603 | 10R | RESC0603(1608)_L |  | C22859 |  | Fitted | No
power MOSFET.kicad_sch | R17 | 39k(0402) | 0402 | 33k | RESC1005X40X25ML05T05 |  | C25779 |  | Fitted | Yes
power MOSFET.kicad_sch | R18 | 39k(0402) | 0402 | 33k | RESC1005X40X25ML05T05 |  | C25779 |  | Fitted | Yes
power MOSFET.kicad_sch | R19 | 39k(0402) | 0402 | 33k | RESC1005X40X25ML05T05 |  | C25779 |  | Fitted | Yes
power MOSFET.kicad_sch | R20 | 10R | 0603 | 10R | RESC0603(1608)_L |  | C22859 |  | Fitted | No
power MOSFET.kicad_sch | R21 | 10R | 0603 | 10R | RESC0603(1608)_L |  | C22859 |  | Fitted | No
power MOSFET.kicad_sch | R22 | 10R | 0603 | 10R | RESC0603(1608)_L |  | C22859 |  | Fitted | No
power MOSFET.kicad_sch | R23 | 0.01R | 2512 | 0.01R | FP-CRCW2512-e3-MFG | RLP25FEER010 | C316229 |  | Fitted | No
power MOSFET.kicad_sch | R24 | 0.01R | 2512 | 0.01R | FP-CRCW2512-e3-MFG | RLP25FEER010 | C316229 |  | Fitted | No
power MOSFET.kicad_sch | R25 | 2k2(0402) | 0402 | 2k | RESC1005X40X25ML05T05 | 0402WGF2001TCE | C4109 | Basic | Fitted | Yes
power MOSFET.kicad_sch | R26 | 2k2(0402) | 0402 | 2k | RESC1005X40X25ML05T05 | 0402WGF2001TCE | C4109 | Basic | Fitted | Yes
power MOSFET.kicad_sch | R27 | 2k2(0402) | 0402 | 2k | RESC1005X40X25ML05T05 | 0402WGF2001TCE | C4109 | Basic | Fitted | Yes
power MOSFET.kicad_sch | U2 | LP2985-33DBVR | SOT-23-5 | LP2985-33DBVR | TI-DBV5_V |  | C95414 |  | Fitted | No
rotor angle sensor.kicad_sch | C39 | 100nF(0402) | 0402 | 100nF | CAPC0402(1005)60_L | CL05B104KB54PNC | C307331 | Basic | Fitted | No
rotor angle sensor.kicad_sch | C40 | 100nF(0402) | 0402 | 100nF | CAPC0402(1005)60_L | CL05B104KB54PNC | C307331 | Basic | Fitted | No
rotor angle sensor.kicad_sch | P6 | SM05B-SRSS-TB |  | SM05B-SRSS-TB | SH-5P-SIDE | SM05B-SRSS-TB |  |  | DNP / manual | No
rotor angle sensor.kicad_sch | R28 | 0R(0402) | 0402 | 0R | RESC1005X40X25ML05T05 | 0402WGF0000TCE | C17168 | Basic | DNP / manual | No
rotor angle sensor.kicad_sch | R29 | 0R(0402) | 0402 | 0R | RESC1005X40X25ML05T05 | 0402WGF0000TCE | C17168 | Basic | DNP / manual | No
rotor angle sensor.kicad_sch | R30 | 0R(0402) | 0402 | 0R | RESC1005X40X25ML05T05 | 0402WGF0000TCE | C17168 | Basic | DNP / manual | No
rotor angle sensor.kicad_sch | U3 | AS5047P |  | AS5047P | TSSOP-14 | AS5047P-ATSM | C962063 |  | Fitted | No

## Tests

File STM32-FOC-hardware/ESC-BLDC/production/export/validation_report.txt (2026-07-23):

STM32 FOC JLCPCB production validation
========================================
Schematics checked: 5
Assembled non-power references: 118
References with LCSC: 118
BOM references exported: 118
CPL references exported: 118

Issue summary:
  ERROR: 0
  WARNING: 0
  MISSING: 0

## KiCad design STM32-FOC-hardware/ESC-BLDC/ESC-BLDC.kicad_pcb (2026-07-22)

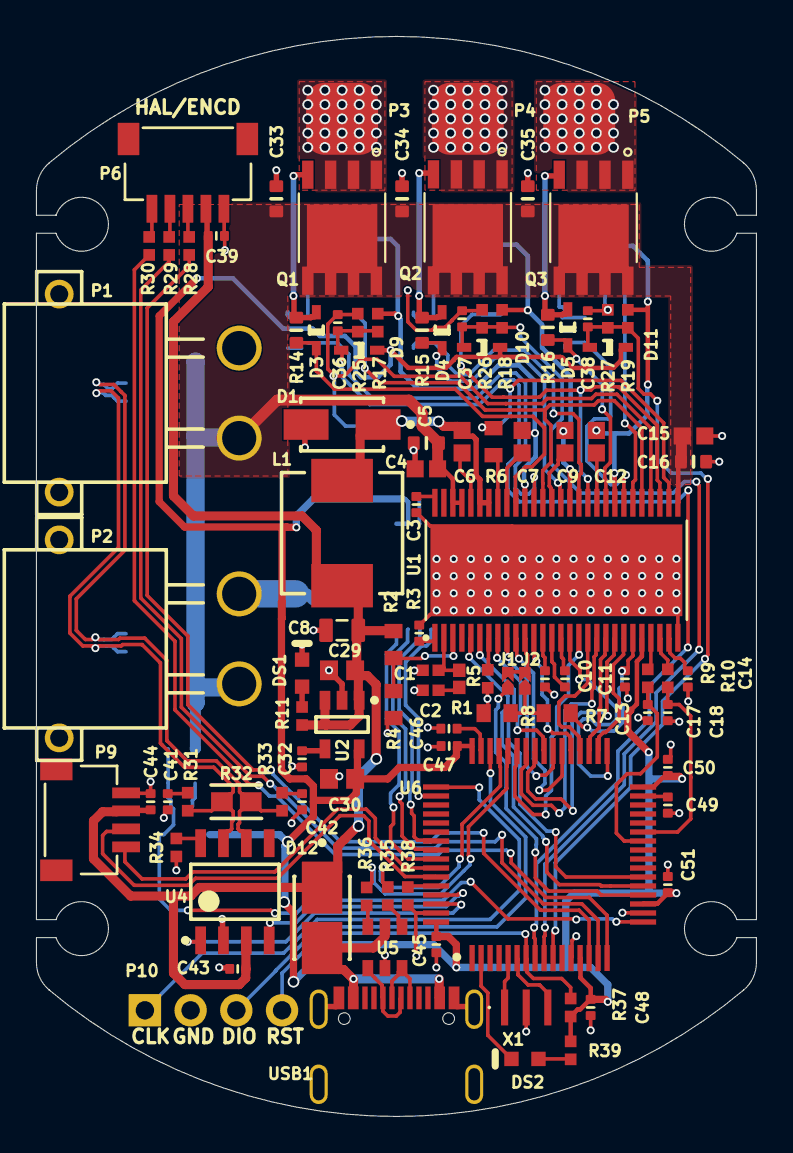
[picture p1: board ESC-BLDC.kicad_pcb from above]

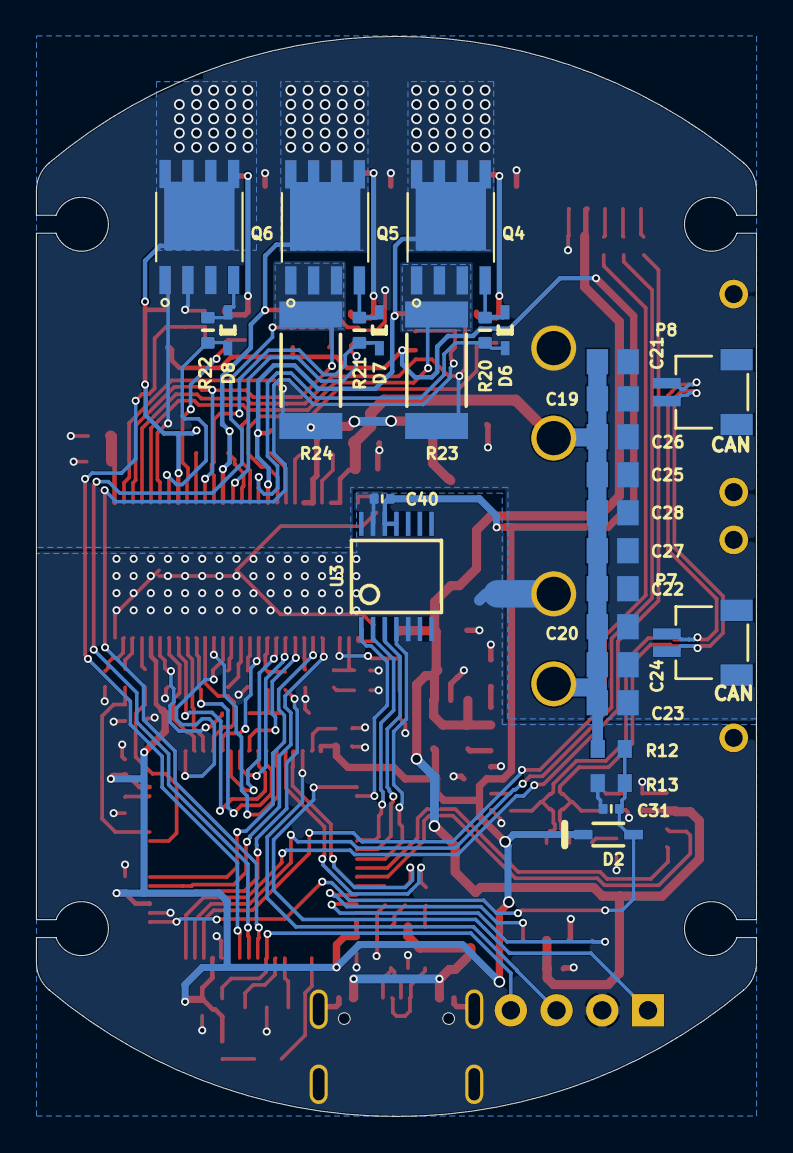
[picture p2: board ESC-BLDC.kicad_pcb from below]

Board: 2 copper layers, 40.0 x 60.0 mm, 131 parts (29 on the bottom side), 100 nets.

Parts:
C1, C2: Capacitor 6.8 nF +/- 10% 16 V 0402; CAPC1005X56X25NL10T15
C3, C11, C17, C18: Capacitor 22nF +/-20% 10V 0402; CAPC0402(1005)60_L
C4, C6, C7, C9, C12, C15: Capacitor 100 nF +/-10% 50 V 0603; CAPC1608X90X40NL10T20
C5, C16, C33, C34, C35: Capacitor 4.7µF +/-20% 10V 0603; CAPC0603(1608)100_L
C8: Capacitor 47µF +/-40% 6.3V 0805; CAPC0805(2012)145_L
C10: Capacitor 2,2µF +/-20% 10V 0402; CAPC0402(1005)60_L
C13, C14: Capacitor 1µF +/-20% 10V 0402; CAPC0402(1005)60_L
C19, C20, C21, C22, C23, C24, C25, C26, C27, C28: Capacitor 10 uF +/- 10% 16 V 0805; CAPC2013X135X45NL10T25
C29, C30: Capacitor 1uF +/- 10% 16V 0603; CAPC1608X90X35ML15T15
C31, C36, C37, C38, C39, C40, C41, C42, C43, C44, C45, C46, C47, C48, C49, C50, C51: Capacitor 100nF +/-20% 50V 0402; CAPC0402(1005)60_L
C32: Capacitor 10nF +/-20% 50V 0402; CAPC0402(1005)60_L
D1: B330A-13-F; FP-SMA-MFG
D2: 1N4148WS; FAIR-SOD-323_V
D3, D4, D5, D6, D7, D8, D9, D10, D11: 1N4148WT; FAIR-SOD-523F-2_V
D12: 1N4007 SMD; FP-1N4007_SMD-IPC_A
DS1: HSMH-C190; AVAG-HSMX-C190_V
DS2: LTST-C190KSKT; LTST-C190KSKT_V
J1, J2: JUMPER
L1: 22uH; FP-IHLP-2525CZ-FP_2_413x3-MFG
P1, P2: XT30PW-M
P3, P4, P5: DP-01
P6: JST_SH-05P; SH-5P-SIDE
P7, P8: JST_SH-02P; SH-2P-SIDE
P9: JST_SH-04P; SH-04-SIDE
P10: HEADER-4P; female_header-4p
Q1, Q2, Q3, Q4, Q5, Q6: MDU1512RH; PDFN56
R1: Resistor 15k +/-1% 0402 63 mW; RESC1005X40X25ML10T10
R2, R4, R6, R7, R8, R12, R13: Resistor 10k +/-1% 0603 100 mW; RESC1608X55X25ML10T15
R3: Resistor 200K +/-1 % 0402 63 mW; RESC0402(1005)_L
R5, R9, R10: Resistor 10k +/-1% 0402 100 mW; RESC1005X40X25ML05T05
R11, R17, R18, R19, R25, R26, R27, R28, R29, R30, R31, R33, R34, R35, R36, R37, R38, R39: Resistor 0R +/- 5% 0402 100 mW; RESC1005X40X25ML05T05
R14, R15, R16, R20, R21, R22: Resistor 120R +/-5 % 0603 0.1 W; RESC0603(1608)_L
R23, R24: 0.001R-2512; FP-CRCW2512-e3-MFG
R32: 120R(0603); FP-RMCF0603-IPC_A
U1: DRV8302; HTSSOP-56
U2: LP2985-33DBVR; TI-DBV5_V
U3: AS5047P; TSSOP-14
U4: MCP2551-I/SN; MCHP-SN8_V
U5: USBLC6-2SC6Y; SOT23-6
U6: STM32F405RGT6; QFP50P1200X1200X160-64N
USB1: USB-C; USB-C-A40-00119
X1: 12MHz; MURA-CSTCE_G_V

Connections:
+3V3: C30.2, C40.2, C45.2, C47.2, C48.2, C50.2, C51.2, D2.2, D9.1, D10.1, D11.1, R37.1, R39.1, U1.24, U2.5, U3.11, U3.12, U6.13, U6.19, U6.32, U6.48, U6.64
+5V: C8.1, C29.2, C39.2, C43.2, C44.2, D12.1, L1.2, P6.2, P9.2, R2.2, R11.1, U2.1, U2.3, U4.3
A_SENSE: C36.2, D9.2, R17.1, R25.2, U6.8
BOOT0: R38.1, U6.60
B_SENSE: C37.2, D10.2, R18.1, R26.2, U6.9
CAN1_N: P7.2, P8.2, R32.1, R33.1, U4.6
CAN1_P: P7.1, P8.1, R31.1, R32.2, U4.7
CAN1_RX: U4.4, U6.61
CAN1_TX: U4.1, U6.62
C_SENSE: C38.2, D11.2, R19.1, R27.2, U6.10
DC_CAL: U1.12, U6.37
EN_GATE: U1.16, U6.33
GAIN: U1.10, U6.38
GH_A: D3.1, R14.1, U1.47
GH_B: D4.1, R15.1, U1.42
GH_C: D5.1, R16.1, U1.37
GL_A: D6.1, R20.1, U1.45
GL_B: D7.1, R21.1, U1.40
GL_C: D8.1, R22.1, U1.35
GND: C1.1, C2.1, C3.2, C4.2, C5.2, C8.2, C10.2, C13.2, C14.2, C15.2, C16.2, C17.2, C18.2, C19.1, C20.1, C21.1, C22.1, C23.1, C24.1, C25.1, C26.1, C27.1, C28.1, C29.1, C30.1, C31.1, C32.1, C33.2, C34.2, C35.2, C36.1, C37.1, C38.1, C39.1, C40.1, C41.1, C42.1, C43.1, C44.1, C45.1, C46.1, C47.1, C48.1, C49.1, C50.1, C51.1, D1.2, DS1.2, P1.2, P2.2, P6.1, P9.1, P10.2, Q6.1, Q6.2, Q6.3, R3.1, R4.1, R5.2, R6.2, R8.1, R13.2, R23.2, R24.2, R25.1, R26.1, R27.1, R34.1, R38.2, U1.28, U1.30, U1.32, U1.34, U1.EXP, U2.2, U3.5, U3.13, U4.2, U5.2, U6.12, U6.18, U6.63, USB1.1, USB1.12, USB1.A, USB1.B, USB1.C, USB1.D, X1.2
HAL_A: R28.2, U6.14
HAL_B: R29.2, U6.15
HAL_C: R30.2, U6.16
INH_A: U1.17, U6.43
INH_B: U1.19, U6.42
INH_C: U1.21, U6.41
INL_A: U1.18, U6.36
INL_B: U1.20, U6.35
INL_C: U1.22, U6.34
LED: DS2.2, U6.2
M_OC: U1.9, U6.39
M_PWM: U1.8, U6.40
NRST: P10.4, R37.2, U6.7
NetC1_2: C1.2, R1.2, U1.2
NetC2_2: C2.2, R1.1
NetC3_1: C3.1, U1.56
NetC6_1: C6.1, U1.52
NetC6_2: C6.2, D1.1, L1.1, U1.50, U1.51
NetC7_1: C7.1, U1.48
NetC9_1: C9.1, U1.43
NetC10_1: C10.1, U1.13
NetC11_1: C11.1, U1.14
NetC11_2: C11.2, U1.15
NetC12_1: C12.1, U1.38
NetC13_1: C13.1, R7.2, U1.23
NetC14_1: C14.1, U1.27
NetC32_2: C32.2, U2.4
NetC41_2: C41.2, R31.2
NetC42_2: C42.2, R33.2
NetC46_2: C46.2, U6.47
NetC49_2: C49.2, U6.31
NetD3_2: D3.2, Q1.4, R14.2
NetD4_2: D4.2, Q2.4, R15.2
NetD5_2: D5.2, Q3.4, R16.2
NetD6_2: D6.2, Q4.4, R20.2
NetD7_2: D7.2, Q5.4, R21.2
NetD8_2: D8.2, Q6.4, R22.2
NetDS1_1: DS1.1, R11.2
NetDS2_1: DS2.1, R39.2
NetJ1_2: J1.2, J2.2, U1.11
NetJ2_1: J2.1, R7.1, R8.2
NetP6_3: P6.3, R28.1
NetP6_4: P6.4, R29.1
NetP6_5: P6.5, R30.1
NetR2_1: R2.1, R4.2, U1.3
NetR3_2: R3.2, U1.1
NetR5_1: R5.1, U1.7
NetR6_1: R6.1, U1.49
NetR9_1: R9.1, U1.25
NetR10_1: R10.1, U1.26
NetR34_2: R34.2, U4.8
NetR35_2: R35.2, U5.4
NetR36_2: R36.2, U5.6
NetU5_1: U5.1, USB1.5, USB1.7
NetU5_3: U5.3, USB1.6, USB1.8
OC_ADJ: J1.1, U6.20
OSC_IN: U6.5, X1.1
OSC_OUT: U6.6, X1.3
PVDD: C4.1, C5.1, C15.1, C16.1, C19.2, C20.2, C21.2, C22.2, C23.2, C24.2, C25.2, C26.2, C27.2, C28.2, C33.1, C34.1, C35.1, P1.1, P2.1, Q1.5, Q1.6, Q1.7, Q1.8, Q1.EXT, Q2.5, Q2.6, Q2.7, Q2.8, Q2.EXT, Q3.5, Q3.6, Q3.7, Q3.8, Q3.EXT, R12.1, U1.29, U1.53, U1.54
PV_SENSE: C31.2, D2.1, R12.2, R13.1, U6.17
SH_A: C7.2, P3.X, Q1.1, Q1.2, Q1.3, Q4.5, Q4.6, Q4.7, Q4.8, Q4.EXT, R17.2, U1.46
SH_B: C9.2, P4.X, Q2.1, Q2.2, Q2.3, Q5.5, Q5.6, Q5.7, Q5.8, Q5.EXT, R18.2, U1.41
SH_C: C12.2, P5.X, Q3.1, Q3.2, Q3.3, Q6.5, Q6.6, Q6.7, Q6.8, Q6.EXT, R19.2, U1.36
SL_A: Q4.1, Q4.2, Q4.3, R23.1, U1.33, U1.44
SL_B: Q5.1, Q5.2, Q5.3, R24.1, U1.31, U1.39
SO1: C17.1, R9.2, U6.26
SO2: C18.1, R10.2, U6.27
SPI_CS: U3.1, U6.50
SPI_MISO: U3.3, U6.56
SPI_MOSI: U3.4, U6.57
SPI_SCK: U3.2, U6.55
SWCLK: P10.1, U6.49
SWDIO: P10.3, U6.46
UART1_RX: P9.3, U6.59
UART1_TX: P9.4, U6.58
USB_N: R36.1, U6.44
USB_P: R35.1, U6.45
VBUS: D12.2, U5.5, USB1.2, USB1.11
nFAULT: U1.6, U6.22
nOCTW: U1.5, U6.21

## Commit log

2026-07-22 Add KiCad hardware production package
    [ESC-BLDC.kicad_pcb, ESC-BLDC.kicad_sch, gate driver.kicad_sch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]
2026-07-22 Use 4.7uF Basic capacitor for C10
    [gate driver.kicad_sch, jlcpcb_bom.csv, original_vs_kicad_component_comparison.csv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]
2026-07-22 Restore agreed L1 JLCPCB selection
    [gate driver.kicad_sch, jlcpcb_bom.csv, selection_updates.csv]
2026-07-22 Select stocked L1 inductor for assembly
    [gate driver.kicad_sch, jlcpcb_bom.csv, original_vs_kicad_component_comparison.csv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]
2026-07-22 Exclude unresolved JST connectors from assembly
    [ESC-BLDC.kicad_sch, jlcpcb_bom.csv, main controller.kicad_sch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]
2026-07-22 Audit sourcing symmetry and divider choices
    [original_vs_kicad_component_comparison.csv, power MOSFET.kicad_sch]
2026-07-22 Clarify KiCad production documentation
2026-07-23 Update KiCad version in README.md
2026-07-23 Apply schematic cleanup and sourcing todo
    [ESC-BLDC.kicad_sch, gate driver.kicad_sch, jlcpcb_bom.csv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]
